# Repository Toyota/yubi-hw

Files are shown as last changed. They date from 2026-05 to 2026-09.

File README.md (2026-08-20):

# YUBI - Yielding Universal Bidigital Interface

### Open Source Hardware for Dexterous Manipulation

<p align="center">
  <a href="https://global.toyota/en/mobility/frontier-research/" target="_blank">
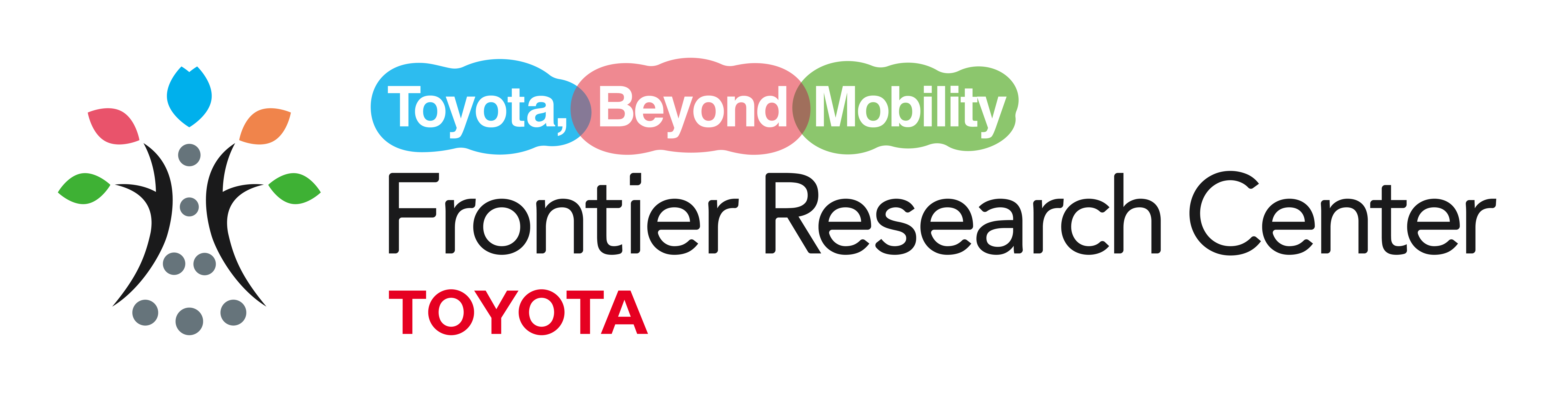
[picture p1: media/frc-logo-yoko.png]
Frontier Research Center, Toyota Motor Corporation
    
  </a>
</p>

<p align="center">
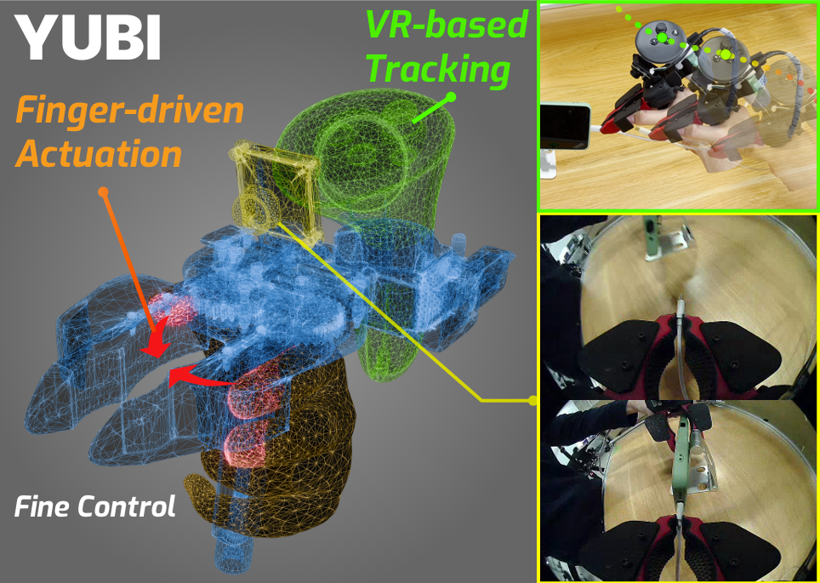
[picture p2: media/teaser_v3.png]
YUBI Overview
  
</p>

🌐 **Project page:** [yubi.airoa.io](https://yubi.airoa.io/)

**YUBI** is a finger-driven dexterous manipulation system developed by Frontier Research Center, Toyota Motor Corporation.

## Part Overview

<p align="center">
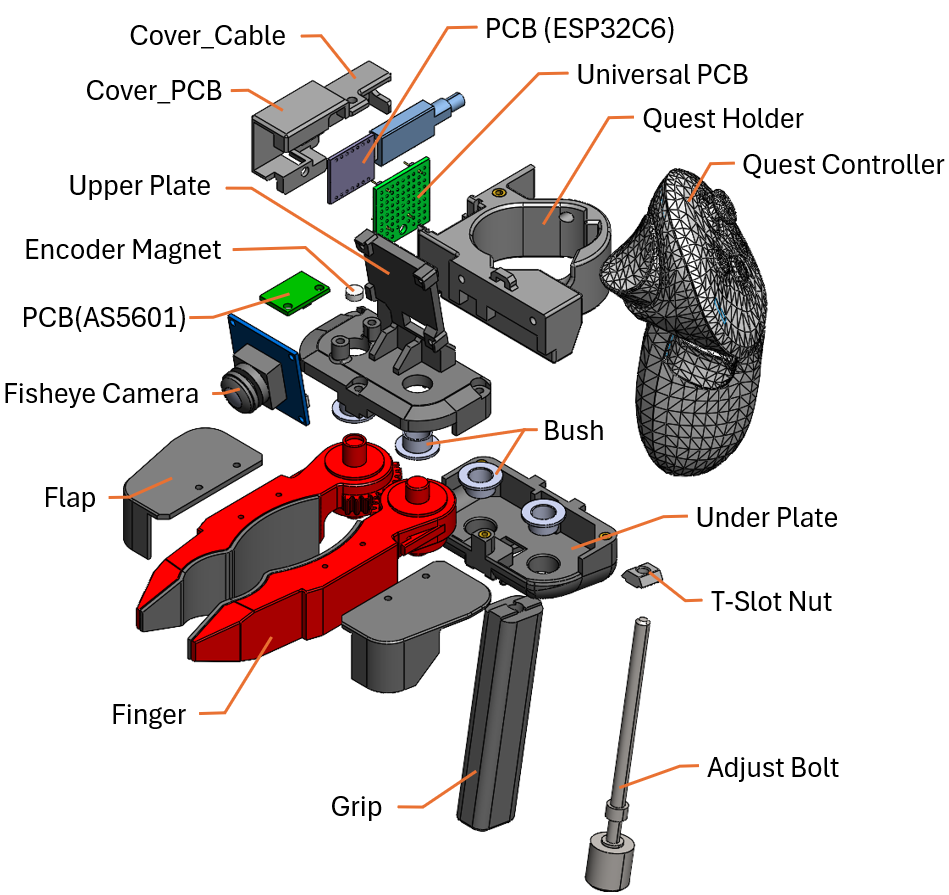
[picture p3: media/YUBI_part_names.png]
YUBI Part Names
  
</p>

- **YUBI Glove** — A wearable device for collecting finger motion data during teleoperation.
- **YUBI Gripper** — A robot-mounted gripper actuated by DYNAMIXEL servos for dexterous manipulation.
- **Stationary data collection desk** — A desk-mounted rig for data collection.
- **Portable data collection rig** — A wearable rig for portable data collection.

<p align="center">
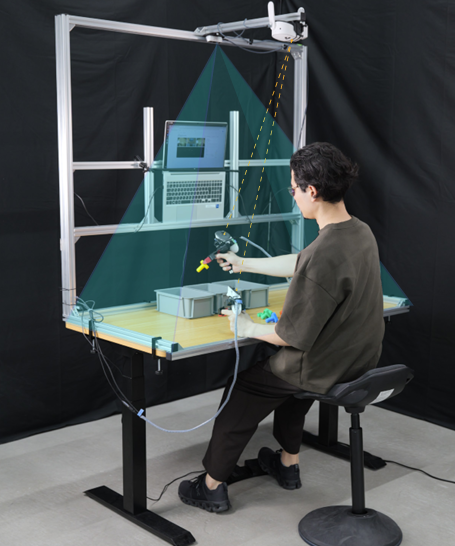
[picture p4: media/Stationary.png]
Stationary data collection desk
  
  &nbsp;&nbsp;
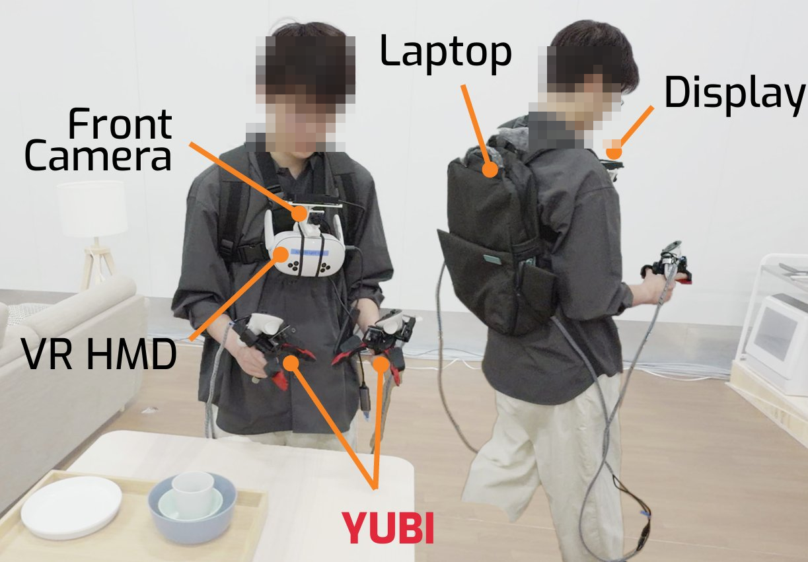
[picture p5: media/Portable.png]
Portable data collection rig
  
</p>

## Repository Structure

```
.
├── STEP/
│   ├── glove/       # YUBI Glove (teleoperation device) STEP files
│   ├── gripper/     # YUBI Gripper (robot-mounted, DYNAMIXEL) STEP files
│   ├── portable/    # Portable data collection rig STEP files
│   └── flange/      # Flange STEP files
├── STL/
│   ├── glove/                  # YUBI Glove STL files (for 3D printing)
│   ├── gripper/                # YUBI Gripper STL files (for 3D printing)
│   ├── portable/               # Portable data collection rig STL files
│   ├── stationary/             # Stationary data collection desk STL files
│   └── flange/                 # Flange STL files
├── docs/
│   ├── BOM/                    # Bill of Materials (CSV)
│   └── AssemblyInstruction/    # Assembly guides (PDF)
└── media/                      # Images for documentation
```

## Supported Robot Flanges

The `flange/` directories provide the parts for mounting the YUBI Gripper to a robot arm. Each supported arm uses a robot-specific flange together with a YUBI-side attachment, as listed below.

| Robot arm | Flange | YUBI-side attachment |
|---|---|---|
| Franka | `FRANKA_FLANGE`  | `YUBI_ATTACHMENT` |
| OpenArm | `OPENARM_FLANGE` | `YUBI_ATTACHMENT` |
| Unitree G1 | `UNITREE_G1_FLANGE` | N/A |

## Getting Started

1. Check the [Bill of Materials](docs/BOM/) to source the required components.
2. 3D print parts using files in the [STL](STL/) directory.
3. Follow the [Assembly Instructions](docs/AssemblyInstruction/) to build the hardware.

## Related Repository

- [yubi-sw](https://github.com/airoa-org/yubi-sw) — Software (control, teleoperation)

## Commercial Use

Commercial manufacturing and sale of products based on YUBI are permitted
subject to CERN-OHL-W v2. See the [Commercial Use Guidelines](COMMERCIAL.md)
for practical guidance.

## Contributors

| Name | Affiliation | Role |
|---|---|---|
| Kazutomo Misao | Frontier Research Center, Toyota Motor Corporation | Project Lead |
| Yoshihiro Okumatsu | Frontier Research Center, Toyota Motor Corporation | Project Sub-Lead |
| Daiki Fukunaga | Frontier Research Center, Toyota Motor Corporation | Mechanical Design |
| Jumpei Arima | Frontier Research Center, Toyota Motor Corporation | Concept Design |
| Yuki Noguchi | Frontier Research Center, Toyota Motor Corporation | Concept Design |
| Makoto Sugiura| AI Robot Association | Data Collection Rig Design |
| Takehiko Ohkawa| AI Robot Association | Data Collection Concept Design |
| Masayoshi Tsuchinaga | Frontier Research Center, Toyota Motor Corporation | Core Maintainer |
| Yusuke Mizuoka | Frontier Research Center, Toyota Motor Corporation | Maintainer |

## Citation

If you use YUBI in your research, please cite:

```bibtex
@misc{ohkawa2026yubi,
      title={{YUBI}: Yielding Universal Bidigital Interface for Bimanual Dexterous Manipulation at Scale},
      author={Takehiko Ohkawa and Jumpei Arima and Yuki Noguchi and Masatoshi Tateno and Makoto Sugiura and Takuya Okubo and Kengo Ikeuchi and Yuma Shin and Hiroki Nishizawa and Naoaki Kanazawa and Yuki Wakayama and Daiki Fukunaga and Koshi Makihara and Tomohiro Motoda and Floris Erich and Yukiyasu Domae and Tatsuya Matsushima and Yoshihiro Okumatsu and Kei Ota},
      year={2026},
      eprint={2606.10244},
      archivePrefix={arXiv},
      primaryClass={cs.RO},
      url={https://arxiv.org/abs/2606.10244},
}
```

## License

This project is licensed under the [CERN Open Hardware Licence Version 2 - Weakly Reciprocal (CERN-OHL-W v2)](LICENSE).

Copyright 2026 Toyota Motor Corporation

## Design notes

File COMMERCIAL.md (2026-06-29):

# Commercial Use Guidelines

This project is released as Open Source Hardware under the
[CERN Open Hardware Licence Version 2 - Weakly Reciprocal
(CERN-OHL-W v2)](LICENSE).

You are free to manufacture, assemble, and sell products based on this
design. However, compliance with the license is required when distributing
Covered Source or products based on it.

This document is a practical summary, not legal advice or a replacement for
the license. If this document and the official license terms differ, the
official license terms control.

## 1. Summary

You are allowed to:

- manufacture products based on this design;
- assemble and sell hardware commercially; and
- integrate this design into larger systems.

When distributing Covered Source or products based on it, you must comply
with the conditions described below and with CERN-OHL-W v2.

## 2. Mandatory Requirements (License Compliance)

### 2.1 License Notice and Attribution

When distributing Covered Source or products based on it, retain the
applicable notices and provide:

- a reference to the CERN-OHL-W v2 license;
- a reference to the original YUBI project; and
- the applicable Source Location.

Example:

```text
This product is based on the YUBI open-source hardware project.
Licensed under CERN-OHL-W v2.
Source: https://github.com/Toyota/yubi-hw
```

### 2.2 Access to Source

When distributing a product based on YUBI, you must either:

- provide each recipient with a copy of the Complete Source; or
- notify each recipient where the Complete Source can be obtained.

For an unmodified YUBI product, the original Source Location is:

<https://github.com/Toyota/yubi-hw>

A Source Location should be a location that you reasonably believe will
remain easily accessible for at least three years, as defined by
CERN-OHL-W v2.

### 2.3 Modifications (If Applicable)

You may modify the design. If you distribute modified Covered Source or a
product based on it:

- you must make the modified Covered Source available as required by the
  license; and
- the modified Covered Source must be licensed under CERN-OHL-W v2 or
  another version permitted by the license.

### 2.4 Change Documentation

When distributing modified Covered Source, you must clearly state:

- who made the changes;
- the date of the changes; and
- a brief description of what was changed.

Example:

```text
Modified by [Company or Individual Name] on [YYYY-MM-DD].
Changes:
- Modified the finger joint geometry
- Reinforced structural components

Modified Source:
https://example.com/path/to/source
```

### 2.5 Copyright Notice

The design files and documentation are copyrighted. You must:

- preserve applicable existing copyright notices; and
- clearly indicate the original copyright holder.

Example:

```text
Copyright 2026 Toyota Motor Corporation
```

Copyright ownership does not prevent use or commercial sale. Rights to use,
make, and sell products are granted subject to CERN-OHL-W v2.

### 2.6 Trademark Usage and Branding

The Toyota name, Toyota logos, and associated marks are protected. This
project and CERN-OHL-W v2 do not grant trademark rights.

You must NOT:

- represent your product as an official Toyota product;
- use Toyota logos in products or marketing without authorization; or
- imply endorsement, certification, sponsorship, or involvement by Toyota
  Motor Corporation.

If you refer to Toyota Motor Corporation or YUBI in product documentation
or marketing, clearly distinguish your product from the original project.
We recommend including a disclaimer such as:

```text
This product is based on the YUBI open-source hardware project.
Toyota Motor Corporation does not endorse or certify this product.
```

Acceptable factual reference:

```text
Based on the YUBI open-source hardware project
```

Unacceptable claims include:

```text
Toyota official product
Toyota-certified hardware
```

## 3. What You Are Allowed to Do

Subject to CERN-OHL-W v2 and any other applicable rights, you may:

- sell assembled hardware products;
- set your own price;
- combine YUBI with proprietary components or systems; and
- use, make, offer to sell, sell, import, and otherwise transfer products
  based on the Covered Source.

No royalties are required by Toyota Motor Corporation for rights granted
under CERN-OHL-W v2.

## 4. What You Are Not Required to Do

CERN-OHL-W v2 does not necessarily require you to:

- open source your entire product;
- open source unrelated components or External Material.

Modified Covered Source remains subject to the license requirements.
Available Components and External Material are treated according to the
definitions and conditions in CERN-OHL-W v2.

## 5. Safety and Liability

The original authors provide the Covered Source and products "as is",
without warranties, as described in CERN-OHL-W v2.

If you manufacture, distribute, or sell a product based on YUBI, you are
responsible for:

- product quality;
- product safety;
- testing and quality assurance;
- compliance with applicable laws, regulations, and standards; and
- claims, warranties, and support offered for your product.

Example:

```text
This product is provided by [Company Name].
The original authors are not responsible for its safety or liability.
```

## 6. Recommended Best Practices

Although not required, we encourage:

- contributing improvements back to the project;
- publishing modified designs publicly; and
- providing clear documentation to users.

## 7. Contact for Commercial Use

If you plan to manufacture or sell products based on YUBI, we kindly ask
that you contact us:

<yubi-contact@mail.toyota.co.jp>

This contact request is voluntary and is not an additional condition of
CERN-OHL-W v2. Contacting us does not constitute approval, certification,
endorsement, or a separate commercial license.

## 8. Final Note

These guidelines are intended to help companies correctly apply
CERN-OHL-W v2 when using YUBI commercially.

For the official license terms, refer to:

<https://cern-ohl.web.cern.ch/>

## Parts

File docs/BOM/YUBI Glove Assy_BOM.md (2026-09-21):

# csv→md

| YUBI Glove Assy_ver.2_PARTS LIST |  |  |  |  |  |  |  |  |  |
| --- | --- | --- | --- | --- | --- | --- | --- | --- | --- |
| (This BOM contains all parts required to build one YUBI Glove. Select either Right-hand or Left-hand specific parts according to your intended configuration) |  |  |  |  |  |  |  |  |  |
|  |  |  |  |  |  |  |  |  |  |
| ・STANDARD PARTS |  |  |  |  |  |  |  |  |  |
| No. | PART No. | TYPE | PART NAME | Qty. | MATERIAL | Buy(JP) | Link | REMARKS | FILE NAME (STL/STEP) |
| 1 | UPPER PLATE_CAMERA BKT | 3D-PRINTED | UPPER PLATE | 1 | PLA_BLACK | - | - |  | UPPER PLATE_CAMERA BKT |
| 2 | UNDER PLATE | 3D-PRINTED | UNDER PLATE | 1 | PLA_BLACK | - | - |  | UNDER PLATE |
| 3 | FINGER with Gear_t30_R | 3D-PRINTED | FINGER with Gear_t30_R | 1 | PLA_RED | - | - | for Right-hand / Outer side | FINGER with Gear_t30_R |
| 4 | FINGER with Gear_t20_L | 3D-PRINTED | FINGER with Gear_t20_L | 1 | PLA_RED | - | - | for Right-hand / Inner side | FINGER with Gear_t20_L |
| 5 | FINGER with Gear_t30_L | 3D-PRINTED | FINGER with Gear_t30_L | 1 | PLA_RED | - | - | for Left-hand / Outer side | FINGER with Gear_t30_L |
| 6 | FINGER with Gear_t20_R | 3D-PRINTED | FINGER with Gear_t20_R | 1 | PLA_RED | - | - | for Left-hand / Inner side | FINGER with Gear_t20_R |
| 7 | FLAP_R | 3D-PRINTED | FLAP_R | 1 | PLA_BLACK | - | - |  | FLAP_R |
| 8 | FLAP_L | 3D-PRINTED | FLAP_L | 1 | PLA_BLACK | - | - |  | FLAP_L |
| 9 | GRIP | 3D-PRINTED | GRIP | 1 | PLA_BLACK | - | - |  | GRIP |
| 10 | HOLDER_Quest_R | 3D-PRINTED | HOLDER_Quest_R | 1 | PLA_BLACK | - | - | for Right-hand | HOLDER_Quest_R |
| 11 | COVER_PCB_R | 3D-PRINTED | COVER_PCB_R | 1 | PLA_BLACK | - | - | for Right-hand | COVER_PCB_R |
| 12 | COVER_CABLE_R | 3D-PRINTED | COVER_CABLE_R | 1 | PLA_BLACK | - | - | for Right-hand | COVER_CABLE_R |
| 13 | HOLDER_Quest_L | 3D-PRINTED | HOLDER_Quest_L | 1 | PLA_BLACK | - | - | for Left-hand | HOLDER_Quest_L |
| 14 | COVER_PCB_L | 3D-PRINTED | COVER_PCB_L | 1 | PLA_BLACK | - | - | for Left-hand | COVER_PCB_L |
| 15 | COVER_CABLE_L | 3D-PRINTED | COVER_CABLE_L | 1 | PLA_BLACK | - | - | for Left-hand | COVER_CABLE_L |
| 16 | MetaQuestTouchPlus_R | STANDARD | MetaQuestTouchPlus Controller_R | 1 | N/A | amazon | [https://www.amazon.co.jp/dp/B09MJQKS5D?ref=fed_asin_title](https://www.amazon.co.jp/dp/B09MJQKS5D?ref=fed_asin_title) | Right / Standard controller for YUBI (used with Quest 3S) |  |
| 17 | MetaQuestTouchPlus_L | STANDARD | MetaQuestTouchPlus Controller_L | 1 | N/A | amazon | [https://www.amazon.co.jp/dp/B09MJQKS5D?ref=fed_asin_title](https://www.amazon.co.jp/dp/B09MJQKS5D?ref=fed_asin_title) | Left / Standard controller for YUBI (used with Quest 3S) |  |
| 18 | USB CAMERA_ELP-USBFHD01M-L180 | STANDARD | CAMERA | 1 | N/A | ELP | [https://www.webcamerausb.com/elp-high-fps-fisheye-usb-camera-module-with-cmos-ov2710-image-sensor-full-hd-1080p-usb20-web-camerawide-angle-usb-with-camera-p-85.html](https://www.webcamerausb.com/elp-high-fps-fisheye-usb-camera-module-with-cmos-ov2710-image-sensor-full-hd-1080p-usb20-web-camerawide-angle-usb-with-camera-p-85.html) |  |  |
| 19 | ESP32C6 | STANDARD | PCB (ESP32C6) | 1 | N/A | amazon | [https://www.amazon.co.jp/dp/B0FX9MN62Z?ref=fed_asin_title](https://www.amazon.co.jp/dp/B0FX9MN62Z?ref=fed_asin_title) |  |  |
| 20 | AS5601 | STANDARD | PCB (AS5601) | 1 | N/A | switch-science | [https://www.switch-science.com/products/3494](https://www.switch-science.com/products/3494) |  |  |
| 21 | NEODYMIUM MAGNET | STANDARD | NEODYMIUM MAGNET_AS5601 | 1 | N/A | - | - | Included with AS5601 sensor |  |
| 22 | UNIVERSAL PCB | STANDARD | UNIVERSAL PCB | 1 | N/A | digikey | [08808 SparkFun Electronics | 穴あきプロトタイプボード | DigiKey](https://www.digikey.jp/ja/products/detail/sparkfun-electronics/08808/7387401) |  |  |
| 23 | PIN HEADER | STANDARD | PIN HEADER | 4 | N/A | - | - | included with ESP32C6 |  |
| 24 | USB CABLE TYPE-C | STANDARD | USB CABLE TYPE-C | 2 | N/A | amazon | [https://www.amazon.co.jp/dp/B08XJP9GMP?ref=fed_asin_title&th=1](https://www.amazon.co.jp/dp/B08XJP9GMP?ref=fed_asin_title&th=1) |  |  |
| 25 | CB2-6 | STANDARD | CAP BOLT | 4 | SCM435 | MISUMI |  |  |  |
| 26 | CB2.5-6 | STANDARD | CAP BOLT | 2 | SCM435 | MISUMI |  |  |  |
| 27 | CB2.5-8 | STANDARD | CAP BOLT | 2 | SCM435 | MISUMI |  |  |  |
| 28 | CB2.5-15 | STANDARD | CAP BOLT | 3 | SCM435 | MISUMI |  |  |  |
| 29 | CB3-6 | STANDARD | CAP BOLT | 1 | SCM435 | MISUMI |  |  |  |
| 30 | CBSTNR3-5 | STANDARD | ULTRA LOW HEAD CAP BOLT | 2 | SCM435 | MISUMI |  |  |  |
| 31 | LRLM3-6 | STANDARD | KNURLED BOLT | 1 | SCM435 | MISUMI |  |  |  |
| 32 | AJKTNS5-70 | STANDARD | ADJUST BOLT | 1 | S45C | MISUMI |  |  |  |
| 33 | HNTT5-5 | STANDARD | T-SLOT NUT | 1 | S10C | MISUMI |  |  |  |
| 34 | SB-264040 | STANDARD | INSERT | 5 | BRASS | MISUMI |  |  |  |
| 35 | SB-304540 | STANDARD | INSERT | 2 | BRASS | MISUMI |  |  |  |
| 36 | JZF8-5 | STANDARD | BUSH | 4 | POM | MISUMI | [https://jp.misumi-ec.com/vona2/detail/110302640340/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](https://jp.misumi-ec.com/vona2/detail/110302640340/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) |  |  |
| 37 | PX-10H15_HYPER V SHEET | STANDARD | RUBBER SHEET_R | 1 | HYPER V SHEET | MISUMI/ | [https://jp.misumi-ec.com/vona2/detail/223013695214/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](https://jp.misumi-ec.com/vona2/detail/223013695214/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) |  |  |
| 38 | PX-10H15_HYPER V SHEET | STANDARD | RUBBER SHEET_L | 1 |  | NISSHINRUBBER | [https://nisshinrubber-metalcraft.com/products/hyperv%E3%82%B7%E3%83%BC%E3%83%88-px-10h-15-%E8%80%90%E6%B2%B9w270-l270-h1-5mm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](https://nisshinrubber-metalcraft.com/products/hyperv%E3%82%B7%E3%83%BC%E3%83%88-px-10h-15-%E8%80%90%E6%B2%B9w270-l270-h1-5mm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) |  |  |
| 39 | RUBBER BAND No.16 | STANDARD | RUBBER BAND No.16 | 1 | RUBBER | amazon | [https://www.amazon.co.jp/%E3%82%AA%E3%83%BC%E3%83%90%E3%83%B3%E3%83%89-100g%E7%AE%B1-GE-011-%E5%A4%A9%E7%84%B6%E3%82%B4%E3%83%A0-%E5%B0%8F%E3%81%95%E3%81%84%E6%A8%99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](https://www.amazon.co.jp/%E3%82%AA%E3%83%BC%E3%83%90%E3%83%B3%E3%83%89-100g%E7%AE%B1-GE-011-%E5%A4%A9%E7%84%B6%E3%82%B4%E3%83%A0-%E5%B0%8F%E3%81%95%E3%81%84%E6%A8%99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) |  |  |
|  |  |  |  |  |  |  | Note:
These links are provided for convenience only.
Toyota does not endorse specific vendors or guarantee the quality, availability, or accuracy of the listed products. |  |  |
|  |  |  |  |  |  |  |  |  |  |
| ・OPTION PARTS |  |  |  |  |  |  |  |  |  |
| No. | PART No. | TYPE | PART NAME | Qty. | MATERIAL | Buy(JP) | Website | REMARKS | FILE NAME (STL/STEP) |
| 101 | FINGER ATTACHMENT_Glove_R | 3D-PRINTED | FINGER ATTACHMENT_Glove_R | 1 | PLA_BLACK | - |  |  | FINGER ATTACHMENT_Glove_R |
| 102 | FINGER ATTACHMENT_Glove_L | 3D-PRINTED | FINGER ATTACHMENT_Glove_L | 1 | PLA_BLACK | - |  |  | FINGER ATTACHMENT_Glove_L |
| 103 | FINGER PAD_t30_R | 3D-PRINTED | FINGER PAD_t30_R | 1 | PLA_RED | - |  | for Right-hand / Outer side | FINGER PAD_t30_R |
| 104 | FINGER PAD_t30_L | 3D-PRINTED | FINGER PAD_t30_L | 1 | PLA_RED | - |  | for Left-hand / Outer side | FINGER PAD_t30_L |
| 105 | FINGER PAD_t20 | 3D-PRINTED | FINGER PAD_t20 | 1 | PLA_RED | - |  | reversible | FINGER PAD_t20 |
| 106 | FINGER PAD_t30_R_v2 | 3D-PRINTED | FINGER PAD_t30_R_v2 | 1 | PLA_RED | - |  | for Right-hand / Outer side | FINGER PAD_t30_R_v2 |
| 107 | FINGER PAD_t30_L_v2 | 3D-PRINTED | FINGER PAD_t30_L_v2 | 1 | PLA_RED | - |  | for Left-hand / Outer side | FINGER PAD_t30_L_v2 |
| 108 | FINGER PAD_t20_v2 | 3D-PRINTED | FINGER PAD_t20_v2 | 1 | PLA_RED | - |  | reversible | FINGER PAD_t20_v2 |
| 109 | FIN | 3D-PRINTED | FIN | 2 | TPU_ORANGE | - |  | reversible / for FINGER PAD_v2 | FIN |
| 110 | CB2.5-10 | STANDARD | CAP BOLT | 4 | SCM435 | MISUMI |  |  |  |

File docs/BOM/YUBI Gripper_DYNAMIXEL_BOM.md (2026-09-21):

# csv→md

| YUBI Gripper Assy_DYNAMIXEL_ver.2_PARTS LIST |  |  |  |  |  |  |  |  |  |
| --- | --- | --- | --- | --- | --- | --- | --- | --- | --- |
|  |  |  |  |  |  |  |  |  |  |
| No. | PART No. | TYPE | PART NAME | Qty. | MATERIAL | Buy(JP) | Link | REMARKS | FILE NAME (STL/STEP) |
| 1 | UPPER PLATE_CAMERA BKT | 3D-PRINTED | UPPER PLATE | 1 | PLA_BLACK | - |  |  | UPPER PLATE_CAMERA BKT |
| 2 | CASE | 3D-PRINTED | CASE | 1 | PLA_BLACK | - |  |  | CASE |
| 3 | BRACKET_DYNAMIXEL | 3D-PRINTED | BRACKET_DYNAMIXEL | 1 | PLA_BLACK | - |  |  | BRACKET_DYNAMIXEL |
| 4 | FINGER PAD_t30_R | 3D-PRINTED | FINGER PAD_t30_R | 1 | PLA_RED | - |  | for Right-hand / Outer side | FINGER PAD_t30_R |
| 5 | FINGER PAD_t30_L | 3D-PRINTED | FINGER PAD_t30_L | 1 | PLA_RED | - |  | for Left-hand / Outer side | FINGER PAD_t30_L |
| 6 | FINGER PAD_t20 | 3D-PRINTED | FINGER PAD_t20 | 1 | PLA_RED | - |  | reversible | FINGER PAD_t20 |
| 7 | FLAP_R | 3D-PRINTED | FLAP_R | 1 | PLA_BLACK | - |  |  | FLAP_R |
| 8 | FLAP_L | 3D-PRINTED | FLAP_L | 1 | PLA_BLACK | - |  |  | FLAP_L |
| 9 | FINGER ATTACHMENT_R | MACHINED OR PRINTED | FINGER ATTACHMENT_R | 1 | A2024 / PLA_BLACK | MACHINED/3D printing |  |  | FINGER ATTACHMENT_R |
| 10 | FINGER ATTACHMENT_L | MACHINED OR PRINTED | FINGER ATTACHMENT_L | 1 | A2024 / PLA_BLACK | MACHINED/3D printing |  |  | FINGER ATTACHMENT_L |
| 11 | GEAR SHAFT | MACHINED | GEAR SHAFT | 1 | A2024 | MACHINED |  |  | GEAR SHAFT |
| 12 | DYNAMIXEL XM430-W350-R | STANDARD | SERVO MOTOR (DYNAMIXEL XM430-W350-R) | 1 | N/A | ROBOTIS | [https://e-shop.robotis.co.jp/product.php?id=44](https://e-shop.robotis.co.jp/product.php?id=44) |  |  |
| 13 | USB CAMERA_ELP-USBFHD01M-L180 | STANDARD | CAMERA | 1 | N/A | ELP | [https://www.webcamerausb.com/elp-high-fps-fisheye-usb-camera-module-with-cmos-ov2710-image-sensor-full-hd-1080p-usb20-web-camerawide-angle-usb-with-camera-p-85.html](https://www.webcamerausb.com/elp-high-fps-fisheye-usb-camera-module-with-cmos-ov2710-image-sensor-full-hd-1080p-usb20-web-camerawide-angle-usb-with-camera-p-85.html) |  |  |
| 14 | GEAKB1.0-30-6-B-8N-QFC17-M3-LL | STANDARD | SPUR GEAR_z30 | 2 | S45C | MISUMI |  |  |  |
| 15 | SSFRHQ8-20-F6-P5-T6-Q5-KC8-A12 | STANDARD | SHAFT D8 | 1 | SUS304 | MISUMI |  |  |  |
| 16 | MTA05-13ZZ DBS | STANDARD | BEARING | 3 | SUS | MISUMI |  |  |  |
| 17 | WSSAB10-5-1 | STANDARD | WASHER | 3 | A2017 | MISUMI |  |  |  |
| 18 | KEG3-8 | STANDARD | PARALLEL KEY | 2 | S45C | MISUMI |  |  |  |
| 19 | CBSTNR2-5 | STANDARD | ULTRA LOW HEAD CAP BOLT | 8 | SCM435 | MISUMI |  |  |  |
| 20 | CBSTNR2.5-6 | STANDARD | ULTRA LOW HEAD CAP BOLT | 1 | SCM435 | MISUMI |  |  |  |
| 21 | CBSTNR3-8 | STANDARD | ULTRA LOW HEAD CAP BOLT | 4 | SCM435 | MISUMI |  |  |  |
| 22 | CB2-6 | STANDARD | CAP BOLT | 4 | SCM435 | MISUMI |  |  |  |
| 23 | CB2.5-6 | STANDARD | CAP BOLT | 2 | SCM435 | MISUMI |  |  |  |
| 24 | CB2.5-10 | STANDARD | CAP BOLT | 4 | SCM435 | MISUMI |  |  |  |
| 25 | CB2.5-15 | STANDARD | CAP BOLT | 7 | SCM435 | MISUMI |  |  |  |
| 26 | SB-304550 | STANDARD | INSERT | 4 | BRASS | MISUMI |  |  |  |
| 27 | SB-264040 | STANDARD | INSERT | 5 | BRASS | MISUMI |  |  |  |
| 28 | SB-203030 | STANDARD | INSERT | 4 | BRASS | MISUMI |  |  |  |
| 29 | JPBPB2-3 | STANDARD | PIN, LOCATING | 1 | SKS3 | MISUMI |  |  |  |
| 30 | JPDPB2-3 | STANDARD | PIN, LOCATING | 1 | SKS3 | MISUMI |  |  |  |
| 31 | PX-10H15_HYPER V SHEET | STANDARD | RUBBER SHEET_R | 1 | HYPER V SHEET | MISUMI/ | [https://jp.misumi-ec.com/vona2/detail/223013695214/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](https://jp.misumi-ec.com/vona2/detail/223013695214/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) |  |  |
| 32 | PX-10H15_HYPER V SHEET | STANDARD | RUBBER SHEET_L | 1 | HYPER V SHEET | NISSHINRUBBER | [https://nisshinrubber-metalcraft.com/products/hyperv%E3%82%B7%E3%83%BC%E3%83%88-px-10h-15-%E8%80%90%E6%B2%B9w270-l270-h1-5mm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](https://nisshinrubber-metalcraft.com/products/hyperv%E3%82%B7%E3%83%BC%E3%83%88-px-10h-15-%E8%80%90%E6%B2%B9w270-l270-h1-5mm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) |  |  |
| 33 | BRACKET_GRIPPER | MACHINED | BRACKET_GRIPPER | 1 | A2024 | MACHINED |  | for attachment to the UR5e | BRACKET_GRIPPER |
| 34 | UR5e_FLANGE | MACHINED | UR5e_FLANGE | 1 | A2024 | MACHINED |  | for attachment to the UR5e | UR5e_FLANGE |
| 35 | CBE3-8 | STANDARD | CAP BOLT | 8 | SCM435 | MISUMI |  | for attachment to the UR5e |  |
| 36 | CBE6-10 | STANDARD | CAP BOLT | 4 | SCM435 | MISUMI |  | for attachment to the UR5e |  |
| 37 | XDSHC6-P4-L6-B5 | STANDARD | PIN, LOCATING | 1 | SUS316L | MISUMI |  | for attachment to the UR5e |  |
| 38 | JPBPB2-3 | STANDARD | PIN, LOCATING | 1 | SKS3 | MISUMI |  | for attachment to the UR5e |  |
| 39 | JPDPB2-3 | STANDARD | PIN, LOCATING | 1 | SKS3 | MISUMI |  | for attachment to the UR5e |  |
|  |  |  |  |  |  |  | Note:
These links are provided for convenience only.
Toyota does not endorse specific vendors or guarantee the quality, availability, or accuracy of the listed products. |  |  |

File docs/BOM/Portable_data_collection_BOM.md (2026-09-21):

| YUBI Portable data collection rig_PARTS LIST |  |  |  |  |  |  |  |  |  |
| --- | --- | --- | --- | --- | --- | --- | --- | --- | --- |
|  |  |  |  |  |  |  |  |  |  |
|  |  |  |  |  |  |  |  |  | Note:
These links are provided for convenience only.
Toyota does not endorse specific vendors or guarantee the quality, availability, or accuracy of the listed products. |
| No. | PART No. | TYPE | PART NAME | Qty. | MATERIAL | REMARKS | FILE NAME (STL/STEP) | Vendor | Link |
| 1 | chest_mount_3s_hmd | 3D-PRINTED | chest_mount_3s_hmd | 1 | ABS |  | chest_mount_3s_hmd |  |  |
| 2 | Display_case | 3D-PRINTED | Display_case | 1 | ABS |  | Display_case |  |  |
| 3 | Display_plate | 3D-PRINTED | Display_plate | 1 | ABS |  | Display_plate |  |  |
| 4 |  | STANDARD | Laptop | 1 |  |  |  |  |  |
| 5 |  | STANDARD | Quest 3s | 1 |  | 128GB |  | amazon | https://amzn.asia/d/asShIRH |
| 6 | 2.02E+09 | STANDARD | 3.5 inch display | 1 |  |  |  | amazon | https://www.amazon.co.jp/dp/B0DRF9Q566 |
| 7 | ELP-USBFHD01M-L180 | STANDARD | Wrist Camera | 2 |  |  |  | alibaba | https://japanese.alibaba.com/product-detail/ELP-USB-Fisheye-Camera-Wide-angle-1601061809265.html |
| 8 | U3H-H043BK/E | STANDARD | USB hub | 2 |  |  |  | amazon | https://www.amazon.co.jp/dp/B0DVGPF6D5 |
| 9 | Anker 332 | STANDARD | USB-C hub | 1 |  |  |  | amazon | https://www.amazon.co.jp/dp/B0BQMSXFP7 |
| 10 | RAD56 | STANDARD | USB cable C-C (2-pack) | 1 |  |  |  | amazon | https://www.amazon.co.jp/dp/B0CX56FJJ6 |
| 11 | 10495 | STANDARD | USB-A extension cable (1m) | 1 |  |  |  | amazon | https://www.amazon.co.jp/dp/B086ZGYCLD |
| 12 | 10550 | STANDARD | micro HDMI to HDMI cable (1m) | 1 |  |  |  | amazon | https://www.amazon.co.jp/dp/B08P5QSG5M |
| 13 | UG-USBC-25052 | STANDARD | USB Type C to RJ45 | 1 |  |  |  | amazon | https://www.amazon.co.jp/dp/B0CD1FDKT1 |
| 14 | 80421 | STANDARD | LAN cable (1m) | 1 |  |  |  | amazon | https://www.amazon.co.jp/dp/B086DPWMQM |
| 15 | BQ-CC71AM-K | STANDARD | Rechargeable battery & charger set | 1 |  |  |  | amazon | https://amzn.asia/d/0atTDXjR |
| 16 | CB2.5-4 | STANDARD | Hex socket bolt | 2 | SCM435 |  |  | misumi | https://jp.misumi-ec.com/vona2/detail/110300239070/?PNSearch=CB2.5-4 |
| 17 | CB3-6 | STANDARD | Hex socket bolt | 2 | SCM435 |  |  | misumi | https://jp.misumi-ec.com/vona2/detail/110300239070/?HissuCode=CB3-6 |
| 18 | SKNTR5 | STANDARD | M5 nut | 1 |  |  |  | misumi | https://jp.misumi-ec.com/vona2/detail/110300250540/ |
| 19 | CINSTAV/E | STANDARD | Chest strap | 1 |  |  |  | insta360 | https://store.insta360.com/jp/product/chest_strap?c=2034&from=accessory |
| 20 |  | STANDARD | Rubber cord | 1 |  |  |  | amazon | https://www.amazon.co.jp/dp/B08KXVQFQF |
| 21 | DGB-S043BK | STANDARD | Backpack | 1 |  |  |  | amazon | https://www.amazon.co.jp/dp/B095RLRDGR |

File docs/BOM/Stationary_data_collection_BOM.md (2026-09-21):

| YUBI Stationary data collection desk_PARTS LIST |  |  |  |  |  |  |  |  |  |
| --- | --- | --- | --- | --- | --- | --- | --- | --- | --- |
|  |  |  |  |  |  |  |  |  |  |
|  |  |  |  |  |  |  |  |  | Note:
These links are provided for convenience only.
Toyota does not endorse specific vendors or guarantee the quality, availability, or accuracy of the listed products. |
| No. | PART No. | TYPE | PART NAME | Qty. | MATERIAL | REMARKS | FILE NAME (STL/STEP) | Vendor | Link |
| 1 | Quest_mount | 3D-PRINTED | Quest_mount | 1 | PLA_BLACK |  | Quest_mount |  |  |
| 2 | realsense435_mount | 3D-PRINTED | realsense435_mount | 1 | PLA_BLACK |  | realsense435_mount |  |  |
| 3 |  | STANDARD | Laptop | 1 |  |  |  |  |  |
| 4 |  | STANDARD | Quest 3s | 1 |  | 128GB |  | amazon | https://amzn.asia/d/asShIRH |
| 5 |  | STANDARD | Realsense435i | 1 |  |  |  | amazon | https://www.amazon.co.jp/dp/B07MWR2YJB |
| 6 | U3H-H043BK/E | STANDARD | USB hub | 2 |  |  |  | amazon | https://www.amazon.co.jp/dp/B0DVGPF6D5 |
| 7 | PQUSB102401 | STANDARD | USB cable A-C | 4 |  |  |  | amazon | https://www.amazon.co.jp/dp/B0CLPG8Z4T |
| 8 | RAD56 | STANDARD | USB cable C-C (2-pack) | 1 |  |  |  | amazon | https://www.amazon.co.jp/dp/B0CX56FJJ6 |
| 9 | LB-6C6S | STANDARD | Power strip | 1 |  |  |  | amazon | https://www.amazon.co.jp/SAYBOUR-%E5%80%8B%E5%88%A5%E3%82%B9%E3%82%A4%E3%83%83%E3%83%81-%E9%9B%B7%E3%82%AC%E3%83%BC%E3%83%89%E7%AF%80%E9%9B%BB%E3%82%BF%E3%83%83%E3%8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 |
| 10 | BQ-CC71AM-K | STANDARD | Rechargeable battery & charger set | 1 |  |  |  | amazon | https://amzn.asia/d/0atTDXjR |
| 11 | HFS6-3030-1340 | STANDARD | HFS6-3030-1340 | 2 |  | Series 6, Square 30x30mm, 1-row slot, 4-side slot |  | misumi |  |
| 12 | HFS6-3030-730 | STANDARD | HFS6-3030-730 | 2 |  | Series 6, Square 30x30mm, 1-row slot, 4-side slot |  | misumi |  |
| 13 | NEFS6-3030-1400 | STANDARD | NEFS6-3030-1400 | 1 |  | Series 6, N-type, Square 30x30mm, 1-row slot, 4-side slot |  | misumi |  |
| 14 | NEFS6-3030-500 | STANDARD | NEFS6-3030-500 | 2 |  | Series 6, N-type, Square 30x30mm, 1-row slot, 4-side slot |  | misumi |  |
| 15 | NEFS6-3030-625.5 | STANDARD | NEFS6-3030-625.5 | 1 |  | Series 6, N-type, Square 30x30mm, 1-row slot, 4-side slot |  | misumi |  |
| 16 | NEFS6-3060-1200 | STANDARD | NEFS6-3060-1200 | 2 |  | Series 6, N-type, Rectangular 30x60mm, 2-row slot, 4-side slot |  | misumi |  |
| 17 | NEFS6-3060-1340 | STANDARD | NEFS6-3060-1340 | 2 |  | Series 6, N-type, Rectangular 30x60mm, 2-row slot, 4-side slot |  | misumi |  |
| 18 | HBLFSD6 | STANDARD | HBLFSD6 | 10 |  | Reverse bracket with protrusion |  | misumi |  |
| 19 | HBLFSN6 | STANDARD | HBLFSN6 | 31 |  | Reverse bracket with protrusion |  | misumi |  |
| 20 | CBM6-12 | STANDARD | CBM6-12 | 100 | SCM435 | Hex socket bolt for aluminum frame |  | misumi |  |
| 21 | GFC6-3030-B | STANDARD | GFC6-3030-B | 7 |  | Series 6 (slot width 8mm), frame cap for aluminum frame |  | misumi |  |
| 22 | HFC6-3060-B | STANDARD | HFC6-3060-B | 2 |  | Series 6 (slot width 8mm), frame cap for aluminum frame |  | misumi |  |
| 23 | HNTP6-6 | STANDARD | HNTP6-6 | 100 |  | Series 6 (slot width 8mm), post-insert spring nut for 30/60 square aluminum frame |  | misumi |  |
| 24 |  | STANDARD | Foot pedal | 1 |  |  |  | amazon | https://amzn.asia/d/2aQH9AC |
| 25 | C-clamp | STANDARD | Clamp (2-pack) | 3 |  |  |  | amazon | https://www.amazon.co.jp/Refoiner-%E3%83%84%E3%83%BC%E3%83%AB%E5%9B%BA%E5%AE%9A%E7%94%A8/dp/B0FMDF4FQL |
| 26 | SKG-R1070BK | STANDARD | Rubber rope with J-hooks on both ends | 1 |  |  |  | misumi | https://jp.misumi-ec.com/vona2/detail/223013895687/ |
| 27 | AB200-W Black | STANDARD | Cable ties | 1 |  |  |  | amazon | https://www.amazon.co.jp/dp/B000THQ4ZO |
| 28 |  | STANDARD | Rubber cord | 1 |  |  |  | amazon | https://www.amazon.co.jp/dp/B08KXVQFQF |
| 29 | E7 | STANDARD | Flexispot E7 standing desk (top 140x70) | 1 |  |  |  | flexispot | https://www.flexispot.jp/e7-set.html?srsltid=AfmBOopAdXlEPLmeXNZ6NbJayiAJpXR7XQ8RgopcW_UmOQsH_2Mnfeve |

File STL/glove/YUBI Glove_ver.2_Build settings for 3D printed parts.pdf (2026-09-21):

YUBI Glove_ver.2 _ Build settings for 3D printed parts

STL file name | Wall loops | Sparse infill density | Printing orientation
UPPER PLATE_CAMERA BKT.stl | 3 | 30% or more

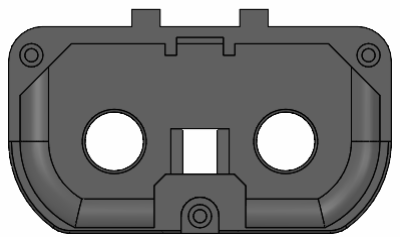
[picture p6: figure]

UNDER PLATE_v2.stl | 3 | 30% or more

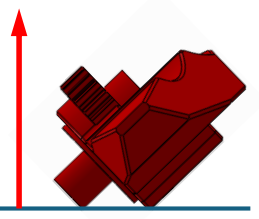
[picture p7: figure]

FINGER with Gear_t30/t20_L.stl | 3 | 50% or more
FINGER with Gear_t30/t20_R.stl | 3 | 50% or more

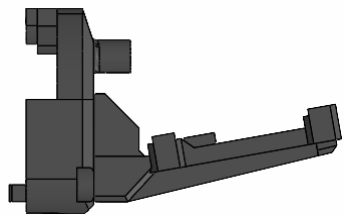
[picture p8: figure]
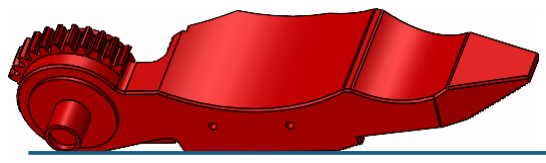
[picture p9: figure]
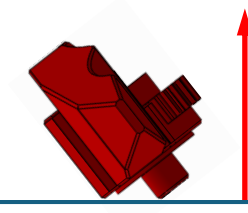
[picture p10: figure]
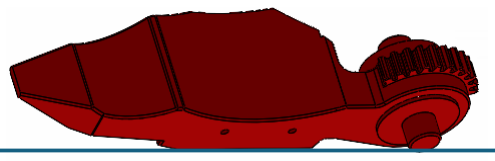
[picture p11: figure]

Other STL data | default | default | Automatic placement is acceptable.

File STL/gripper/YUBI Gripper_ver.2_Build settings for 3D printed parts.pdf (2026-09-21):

YUBI Gripper_ver.2 _ Build settings for 3D printed parts

STL file name | Wall loops | Sparse infill density | Printing orientation
UPPER PLATE_CAMERA BKT.stl | 3 | 50% or more
CASE.stl | 3 | 50% or more

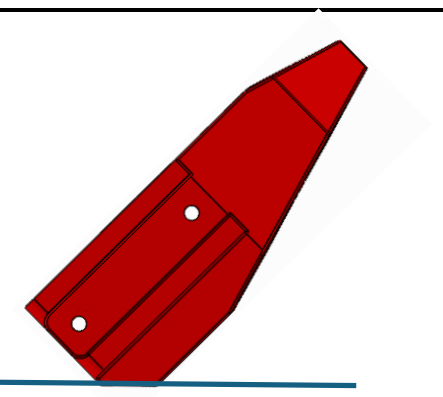
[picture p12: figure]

FINGER PAD_t30_L.stl FINGER PAD_t30_R.stl | 3 | 50% or more
FINGER PAD_t20.stl | 3 | 50% or more

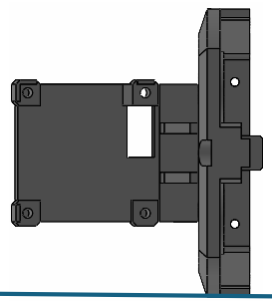
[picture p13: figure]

Other STL data | default | default | Automatic placement is acceptable.

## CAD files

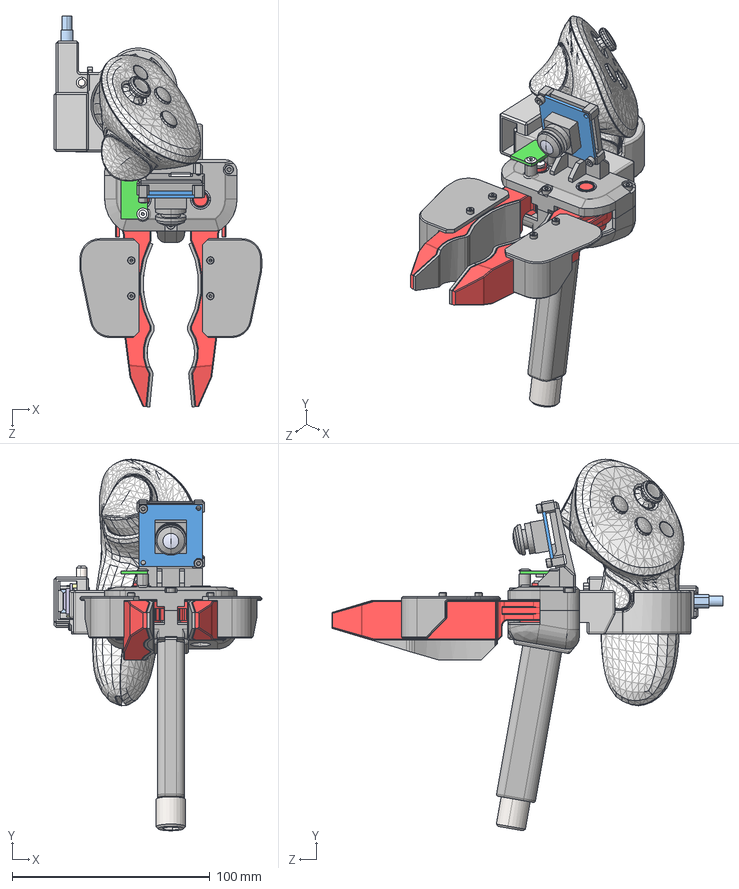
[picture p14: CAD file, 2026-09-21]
STEP/glove/YUBI Glove Assy_ver2_R.STEP
105.0 x 188.0 x 197.8 mm
UNDER PLATE_v2_INSERT TYPE
UPPER PLATE_CAMERA BKT_12bit_AS5601_v2_INSERT TYPE
FINGER with Gear_Glove_t30_R_SHAFT DIA Φ8
FINGER with Gear_Glove_t20_L_SHAFT DIA Φ8
RUBBER SHEET_t30_R
RUBBER SHEET_t20
AS5601
HNTT5-5
GRIP
AJKTNS5-70
USB CAMERA_ELP-USBFHD01M-L180
CBSTNR3-5 x 2
MAGNET_D6_AS5601
FLAP_R
FLAP_L
HOLDER_Quest_45deg_R_INSERT TYPE
COVER1_R
COVER2_R
ESP32
UNIVERSAL PCB
CB2.5-15 x 3
CB2.5-8 x 2
CB3-6
LRLM3-6
CB2-6 x 4
CB2.5-6 x 2
MetaQuestTouchPlus_Right
JZF8-5 x 4
SB-264040 x 5
SB-304540 x 2

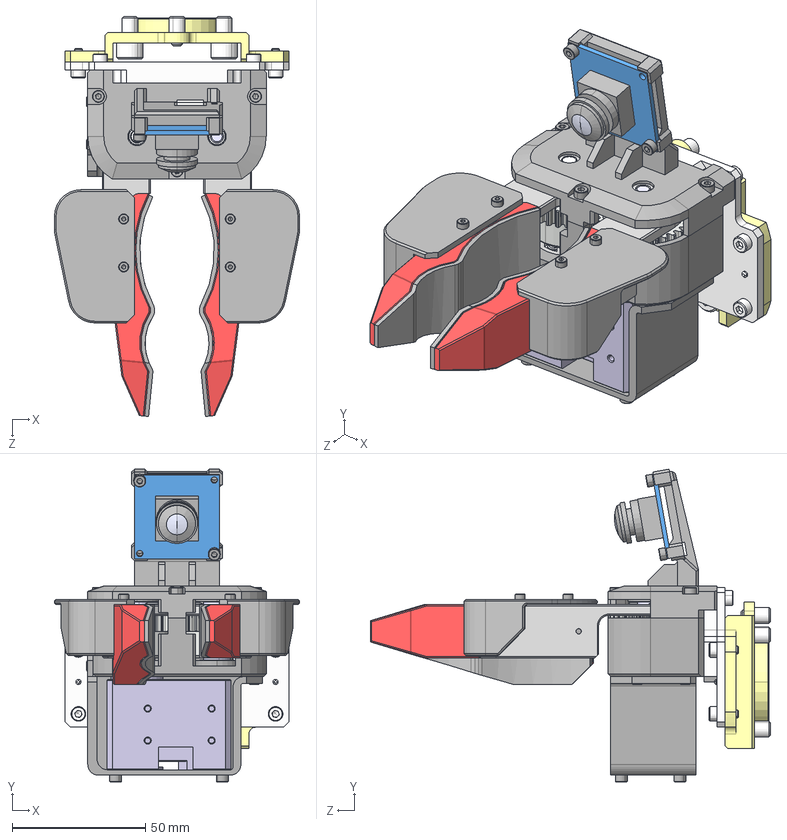
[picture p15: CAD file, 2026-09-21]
STEP/gripper/YUBI Gripper Assy_Dynamixel_ver2.STEP
92.0 x 117.4 x 150.1 mm
BRACKET_DYNAMIXEL
DYNAMIXEL XM430-W350-R
GEAR SHAFT
CASE
MTA05-13ZZ DBS x 3
WSSAB10-5-1 x 3
SSFRHQ8-20-F6-P5-T6-Q5-KC8-A12
GEAKB1.0-30-6-B-8N-QFC17-M3-LL x 2
FINGER ATTACHMENT_R
FINGER ATTACHMENT_L
PAD_t30_R
PAD_t20
RUBBER SHEET_t30_R
RUBBER SHEET_t20
UPPER PLATE_CAMERA BKT
USB CAMERA_ELP-USBFHD01M-L180
FLAP_R
FLAP_L
SB-304550 x 4
SB-264040 x 3
SB-203030 x 4
JPBPB2-3 x 2
JPDPB2-3 x 2
CB2.5-15 x 7
CB2.5-10 x 4
CB2.5-6 x 2
CB2-6 x 4
CBSTNR2-5 x 8
CBSTNR2.5-6
KEG3-8 x 2
CBSTNR3-8 x 4
CBE3-8 x 8
BRACKET_GRIPPER
UR5e_FLANGE
XDSHC6-P4-L6-B5
CBE6-10 x 4

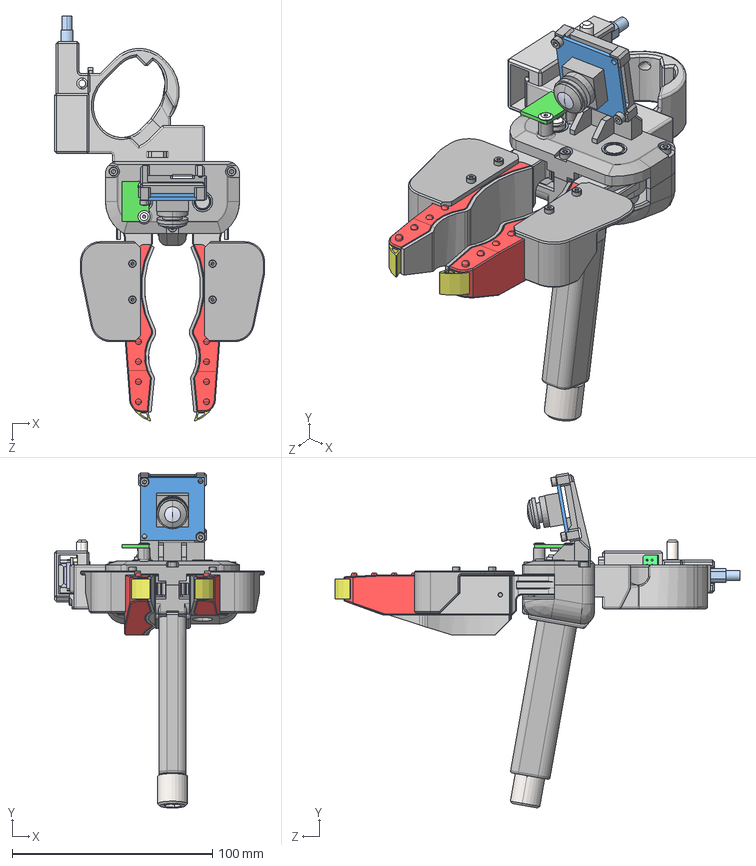
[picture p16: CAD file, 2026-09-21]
STEP/glove/YUBI Glove Assy_ver2_R_opt2.STEP
105.0 x 167.3 x 202.3 mm
UNDER PLATE_v2_INSERT TYPE
UPPER PLATE_CAMERA BKT_12bit_AS5601_v2_INSERT TYPE
FINGER ATTACHMENT_Glove_R_フック位置変更
FINGER ATTACHMENT_Glove_L_フック位置変更
CB2.5-10 x 4
PAD_t30_R_v2
PAD_t20_L_v2
Fin_v1 x 2
RUBBER SHEET_t30_v2_R
RUBBER SHEET_t20_v2_L
AS5601
HNTT5-5
GRIP
AJKTNS5-70
USB CAMERA_ELP-USBFHD01M-L180
CBSTNR3-5 x 2
MAGNET_D6_AS5601
FLAP_R
FLAP_L
HOLDER_Quest_45deg_R_INSERT TYPE
COVER1_R
COVER2_R
ESP32
UNIVERSAL PCB
CB2.5-15 x 3
CB2.5-6 x 4
CB3-6
LRLM3-6
CB2-6 x 4
JZF8-5 x 4
SB-264040 x 5
SB-304540 x 2

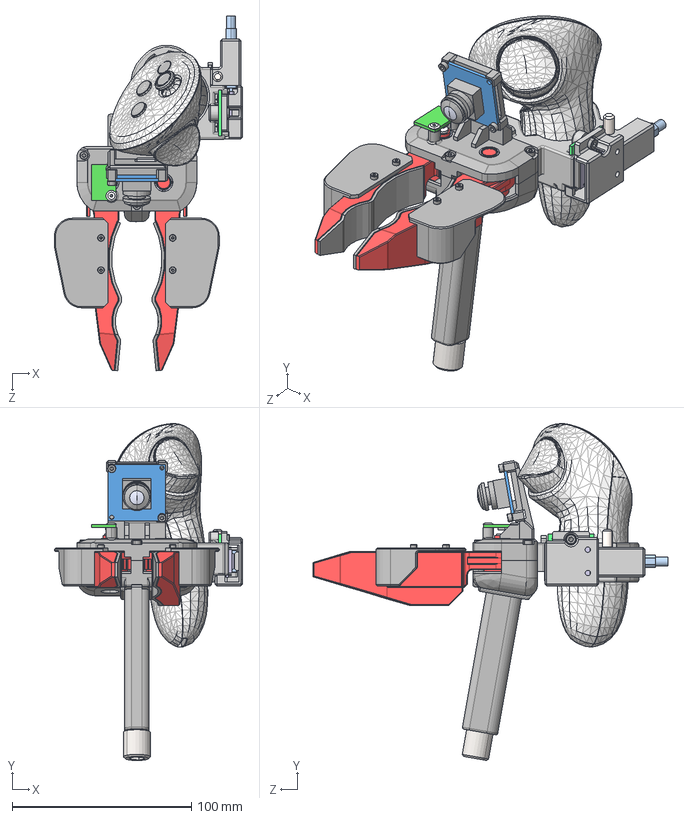
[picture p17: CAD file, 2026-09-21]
STEP/glove/YUBI Glove Assy_ver2_L.STEP
105.0 x 188.0 x 197.8 mm
UNDER PLATE_v2_INSERT TYPE
UPPER PLATE_CAMERA BKT_12bit_AS5601_v2_INSERT TYPE
RUBBER SHEET_t20
RUBBER SHEET_t30_L
AS5601
HNTT5-5
GRIP
AJKTNS5-70
USB CAMERA_ELP-USBFHD01M-L180
CBSTNR3-5 x 2
MAGNET_D6_AS5601
FLAP_R
FLAP_L
HOLDER_Quest_45deg_L_INSERT TYPE
COVER1_L
COVER2_L
ESP32
UNIVERSAL PCB
CB2.5-15 x 3
CB2.5-8 x 2
CB3-6
LRLM3-6
CB2-6 x 4
MetaQuestTouchPlus_Left
FINGER with Gear_Glove_t20_R_SHAFT DIA Φ8
FINGER with Gear_Glove_t30_L_SHAFT DIA Φ8
JZF8-5 x 4
SB-264040 x 5
SB-304540 x 2
CB2.5-6 x 2

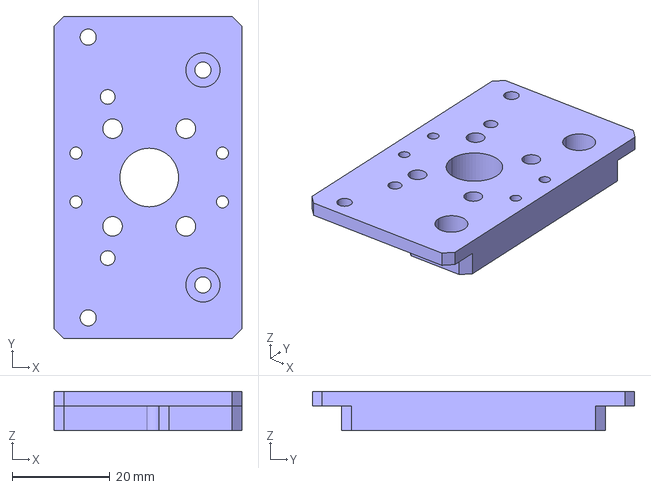
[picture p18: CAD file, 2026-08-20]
STEP/flange/UNITREE_G1_FLANGE.STEP
38.5 x 66.0 x 8.00 mm

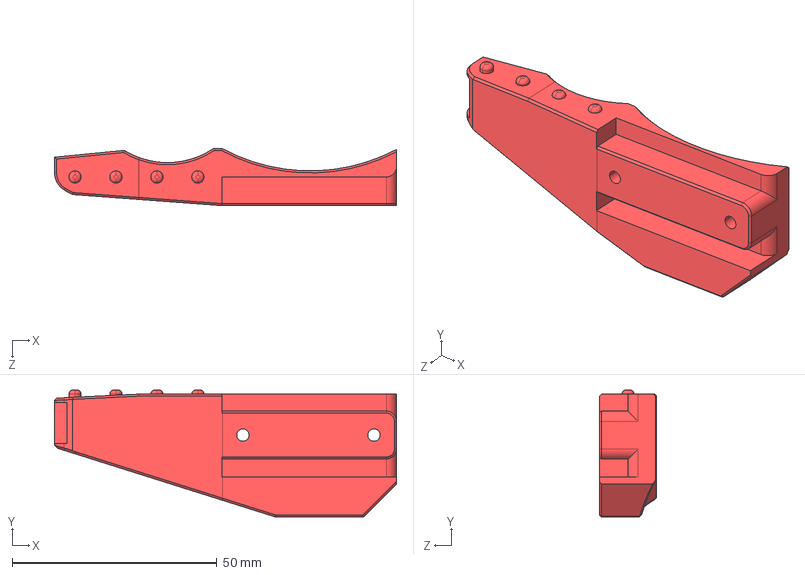
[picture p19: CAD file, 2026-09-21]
STEP/glove/option parts/FINGER PAD_t30_L_v2.STEP
83.5 x 31.0 x 14.0 mm

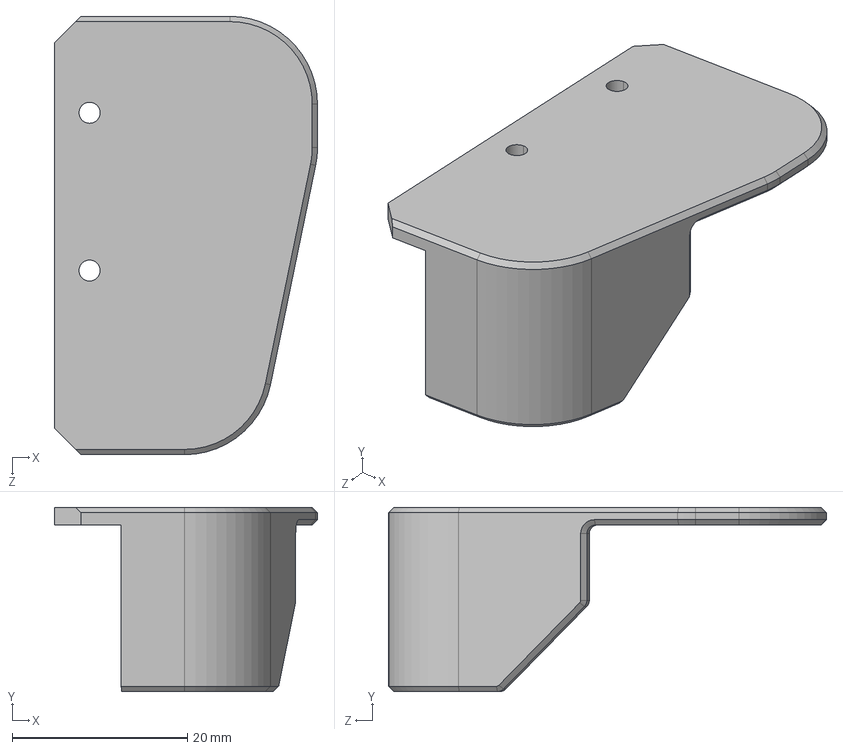
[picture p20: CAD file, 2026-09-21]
STEP/gripper/FLAP_L.STEP
30.0 x 21.0 x 50.0 mm

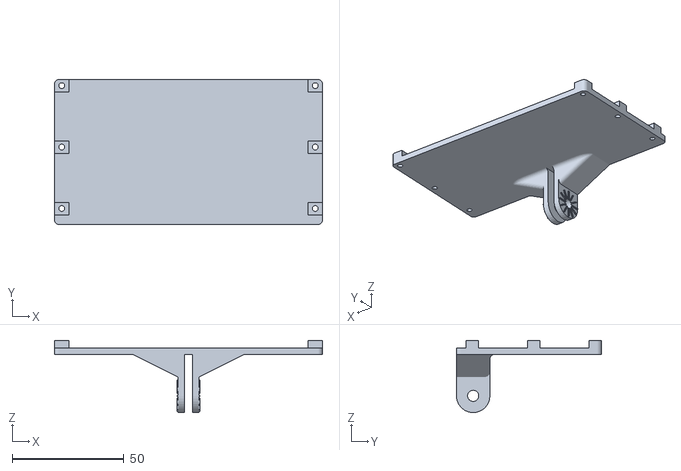
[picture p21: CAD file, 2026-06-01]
STL/portable/Display_plate.stl
120.0 x 65.0 x 32.3

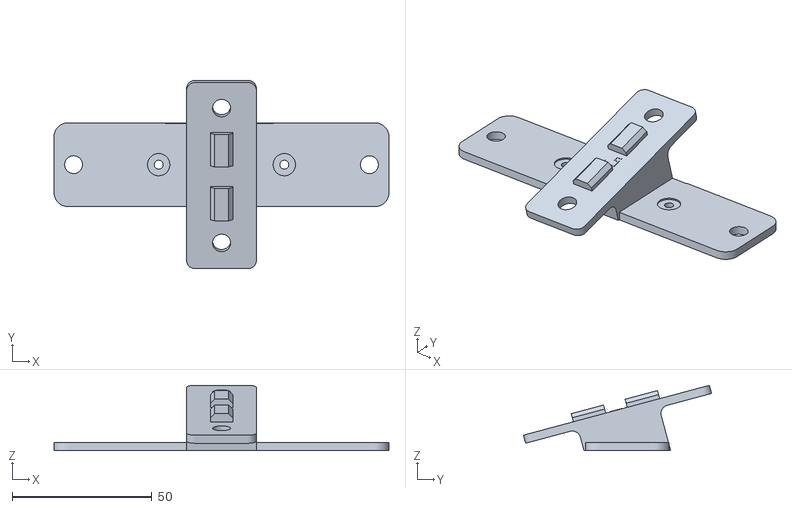
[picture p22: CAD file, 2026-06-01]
STL/stationary/realsense435_mount.stl
120.0 x 67.4 x 23.4

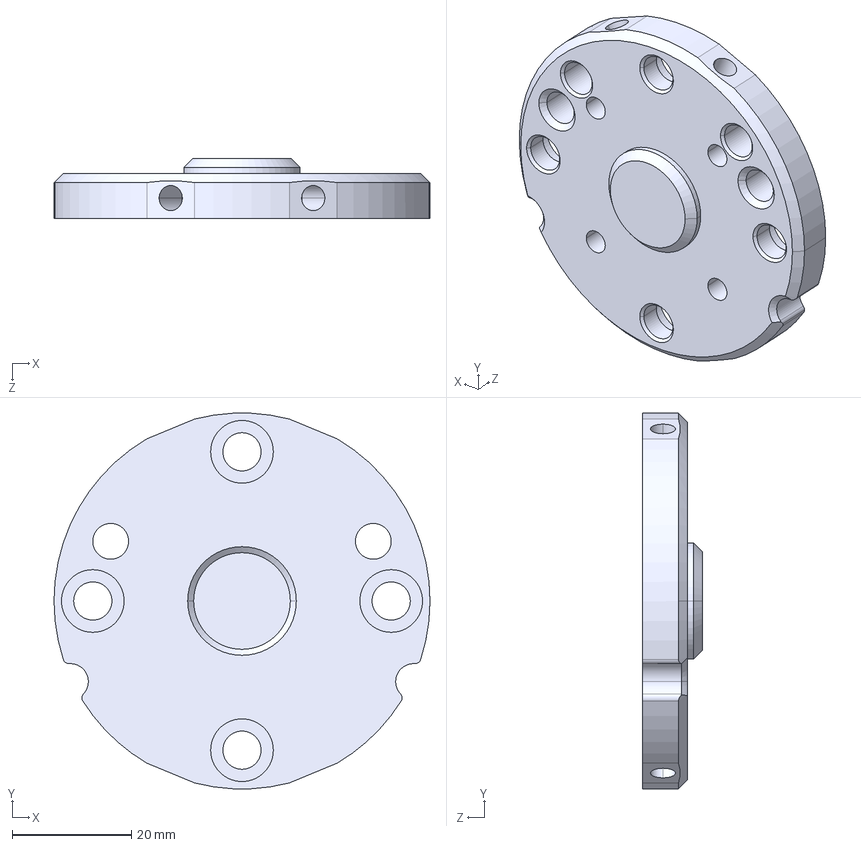
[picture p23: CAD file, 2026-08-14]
STEP/flange/OPENARM_FLANGE.STEP
63.0 x 62.9 x 10.0 mm

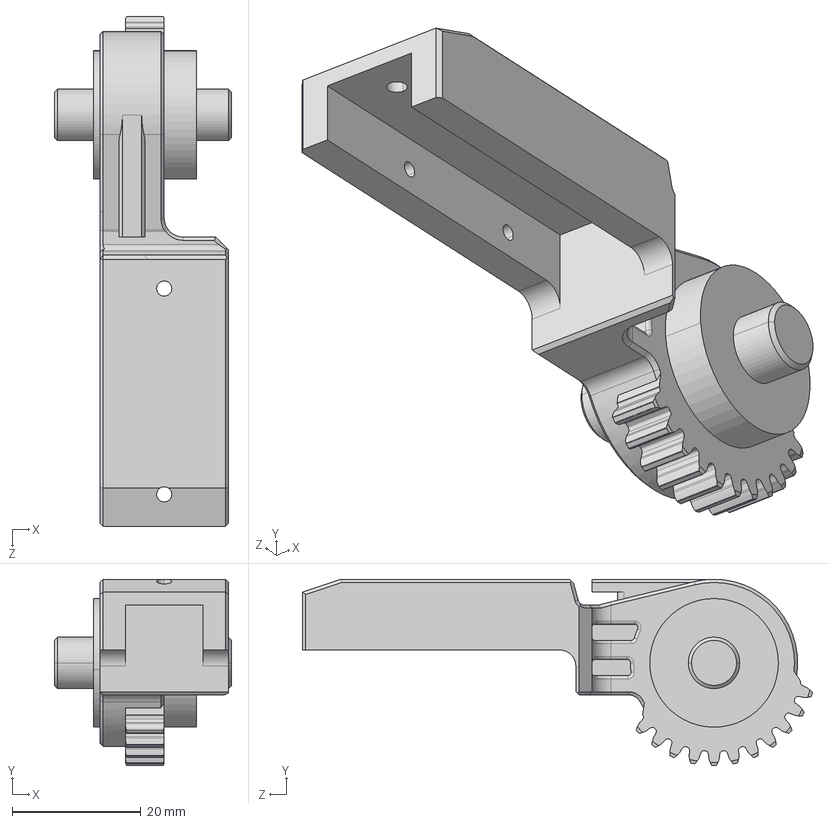
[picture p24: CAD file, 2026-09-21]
STEP/glove/option parts/FINGER ATTACHMENT_Glove_L.STEP
27.6 x 29.0 x 79.3 mm

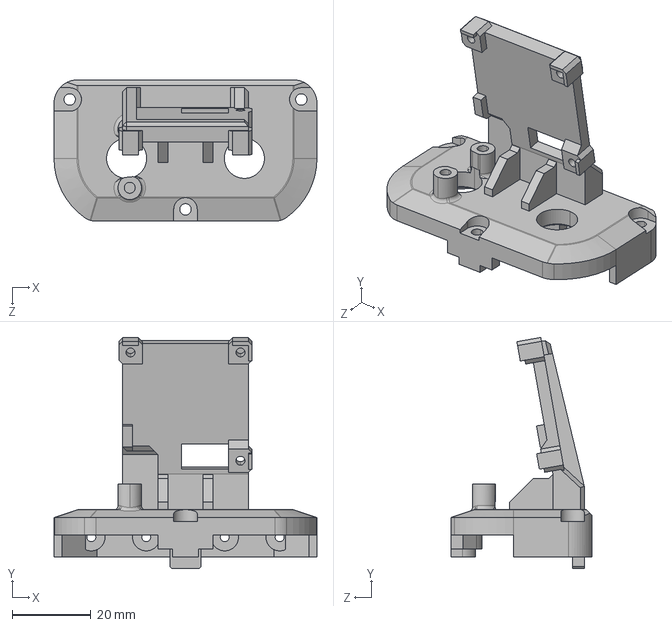
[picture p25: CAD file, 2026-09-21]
STEP/glove/UPPER PLATE_CAMERA BKT.STEP
67.0 x 58.9 x 36.0 mm

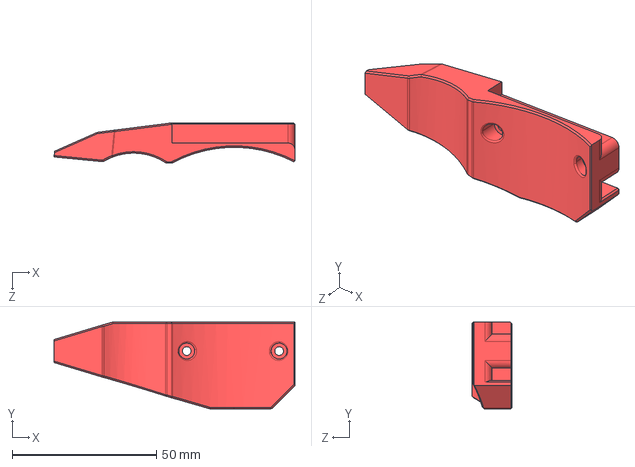
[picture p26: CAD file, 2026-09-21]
STEP/gripper/FINGER PAD_t30_R.STEP
83.5 x 30.0 x 14.0 mm

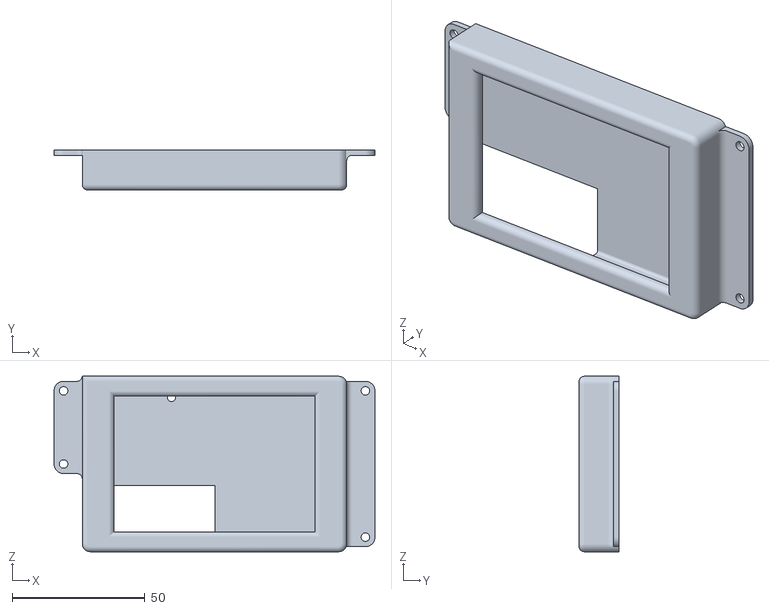
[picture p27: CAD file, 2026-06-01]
STL/portable/Display_case.stl
120.7 x 15.0 x 66.0

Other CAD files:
STEP/glove/YUBI Glove Assy_ver2_R_opt1.STEP
STL/stationary/Quest_mount.stl
STEP/flange/FRANKA_FLANGE.STEP
STEP/flange/YUBI_ATTACHMENT.STEP
STEP/glove/COVER_CABLE_L.STEP
STEP/glove/COVER_CABLE_R.STEP
STEP/glove/COVER_PCB_L.STEP
STEP/glove/COVER_PCB_R.STEP
STEP/glove/FINGER with Gear_t20_L.STEP
STEP/glove/FINGER with Gear_t20_R.STEP
STEP/glove/FINGER with Gear_t30_L.STEP
STEP/glove/FINGER with Gear_t30_R.STEP
STEP/glove/FLAP_R.STEP
STEP/glove/GRIP.STEP
STEP/glove/HOLDER_Quest_L.STEP
STEP/glove/HOLDER_Quest_R.STEP
STEP/glove/UNDER PLATE_v2.STEP
STEP/glove/option parts/FINGER ATTACHMENT_Glove_R.STEP
STEP/glove/option parts/FINGER PAD_t20.STEP
STEP/glove/option parts/FINGER PAD_t20_L_v2.STEP
STEP/glove/option parts/FINGER PAD_t20_R_v2.STEP
STEP/glove/option parts/FINGER PAD_t30_L.STEP
STEP/glove/option parts/FINGER PAD_t30_R_v2.STEP
STEP/glove/option parts/Fin.STEP
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

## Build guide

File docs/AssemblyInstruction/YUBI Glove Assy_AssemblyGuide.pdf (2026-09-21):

YUBI Glove Assy_ver.2 Assembly Procedure

【Assembly Procedure】
(1) Install components onto UPPER PLATE
- Install INSERTs
- Install BUSHINGs
(2) Install components onto UNDER PLATE
- Install INSERTs
- Install BUSHINGs
(3) Install components onto FINGER with Gear_t30_R or t20_R
- Install RUBBER SHEET
- Install ENCODER MAGNET
(4) Install components onto FINGER with Gear_t30_L or t20_L
- Install RUBBER SHEET
(5) Install FINGER with Gear and UPPER PLATE
(6) Install FLAPs | 【YUBI Glove Assy_ver.2_for Right-hand】
- Install FLAP_R
- Install FLAP_L
(7) Install HOLDER_Quest_R/L
- Install INSERTs
- Install HOLDER_Quest_R/L
(8) Install PCB and Wiring
- Install PCB (AS5601) onto UPPER PLATE
- Install PCB (ESP32C6) on HOLDER_Quest_R/L
- Install USB TYPE-C CABLE
(9) Install CAMERA
- Install CAMERA
- Connect CAMERA WIRING

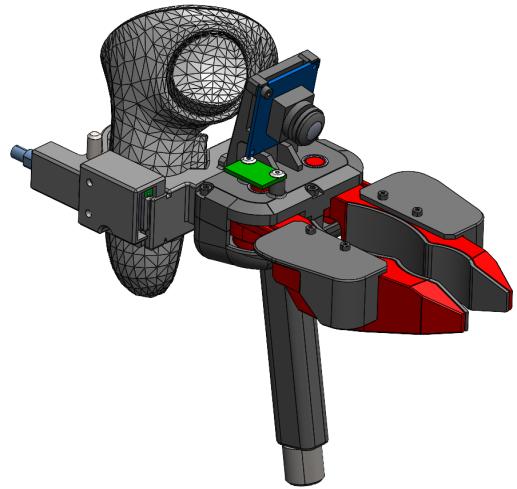
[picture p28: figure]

(10) Install GRIP | 【YUBI Glove Assy_ver.2_for Left-Hand】
- Install T-SLOT NUT
- Install GRIP
- Adjust GRIP position
(11) Install Rubber Band for Finger opening and closing
(12) Install Meta Quest Touch Plus Controller

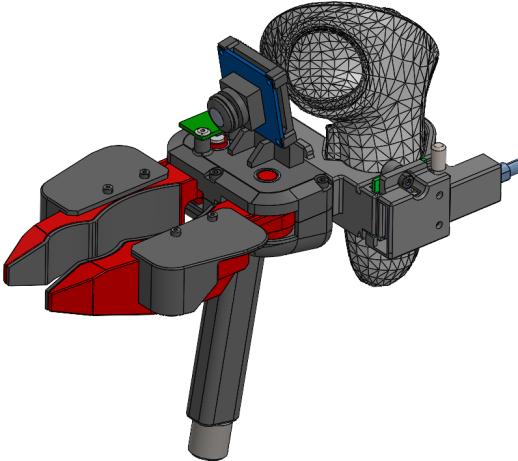
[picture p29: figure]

【Optional Parts Assembly Procedure】
(1) Install FINGER ATTACHMENT_Glove and FINGER PAD

(1) Install components onto UPPER PLATE
- Install INSERTs
Install following INSERTs into UPPER PLATE
① SB-264040: 2 pcs. (Installation positions differ between for right-hand and left-hand versions.)
【for Right-hand Version】 | 【for Left-hand Version】

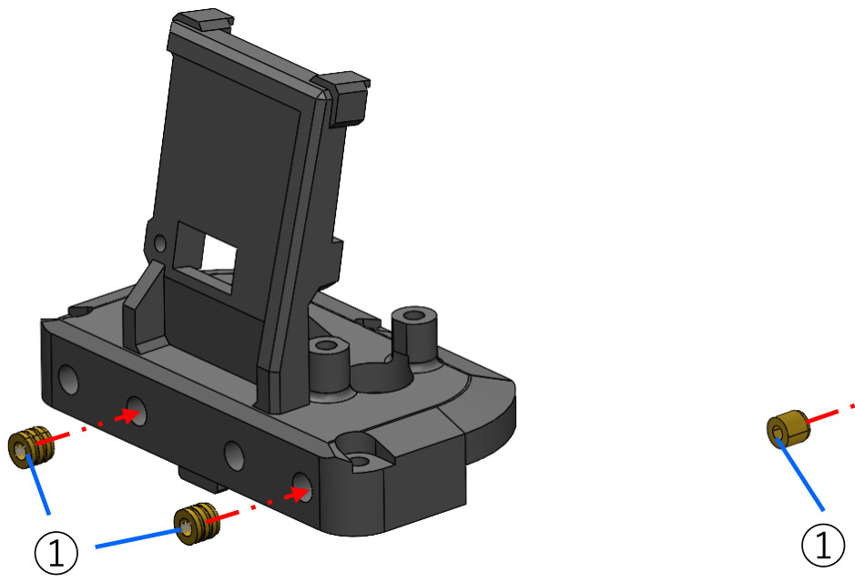
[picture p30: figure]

- Install BUSHINGs
Install following BUSHINGs into UPPER PLATE ② JZF8-5: 2 pcs.

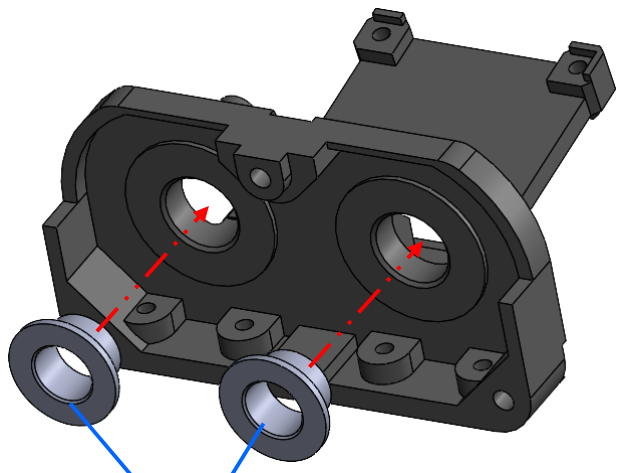
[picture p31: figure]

②

(2) Install components onto UNDER PLATE
- Install INSERTs
Install following INSERTs into UNDER PLATE

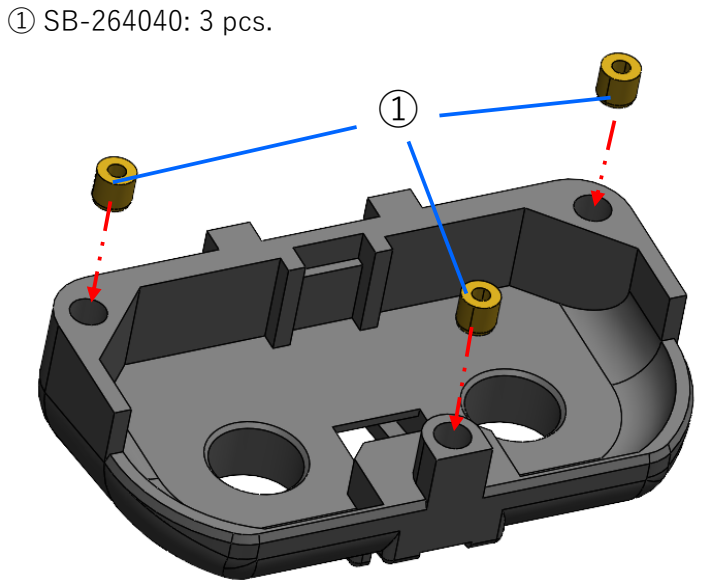
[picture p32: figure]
① SB-264040: 3 pcs.

- Install BUSHINGs
Install following BUSHINGs into UNDER PLATE

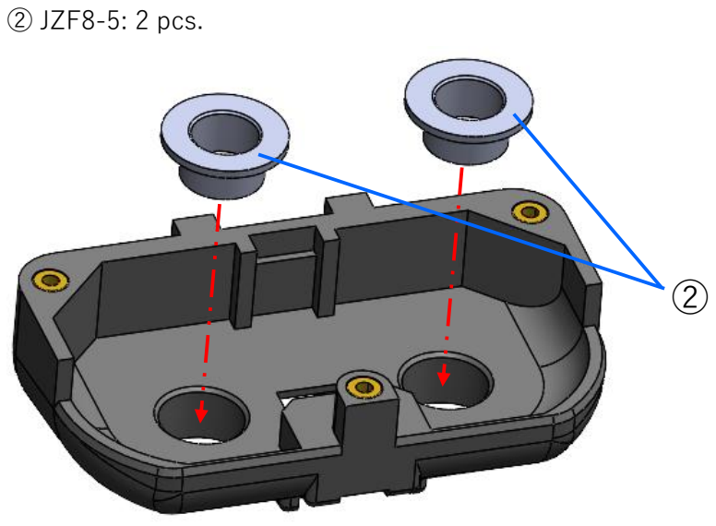
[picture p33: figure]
② JZF8-5: 2 pcs.

(3) Install components onto FINGER with Gear_t30_R or t20_R
- Install RUBBER SHEET
① Attach RUBBER SHEET onto FINGER with Gear_t30_R or t20_R using adhesive (e.g., Super X).
Select RUBBER SHEET size based on gripping location and required area.

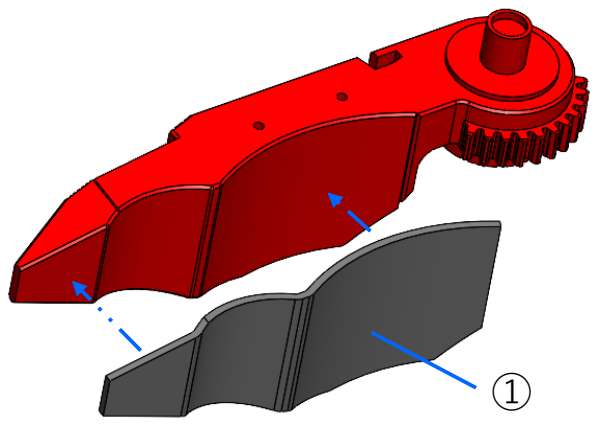
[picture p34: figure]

- Install ENCODER MAGNET
② Attach NEODYMIUM MAGNET_AS5601 to FINGER with Gear_t30_R or t20_R using instant adhesive.

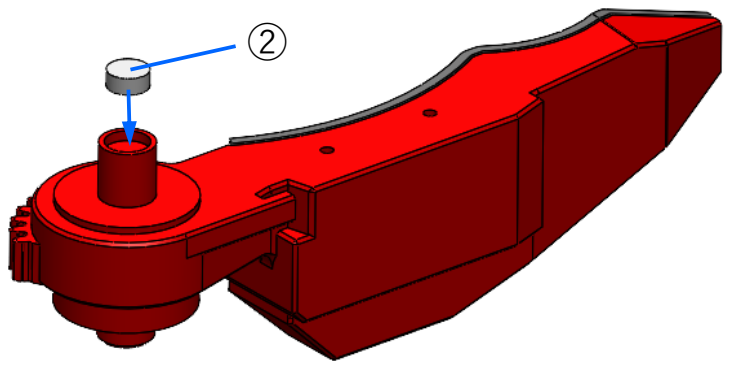
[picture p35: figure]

(4) Install components onto FINGER with Gear_t30_L or t20_L
- Install RUBBER SHEET
① Attach RUBBER SHEET to FINGER with Gear_t30_L or t20_L using adhesive (e.g., Super X).
Select RUBBER SHEET size based on gripping location and required area.

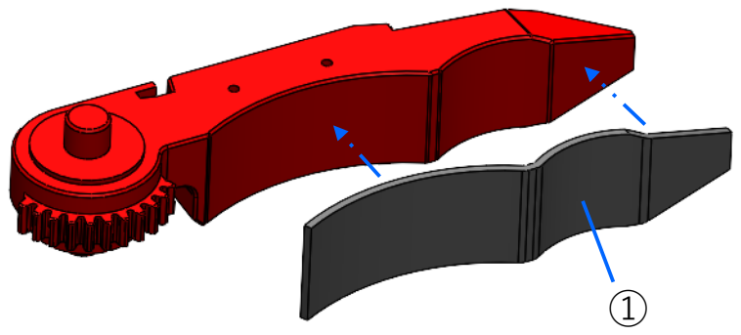
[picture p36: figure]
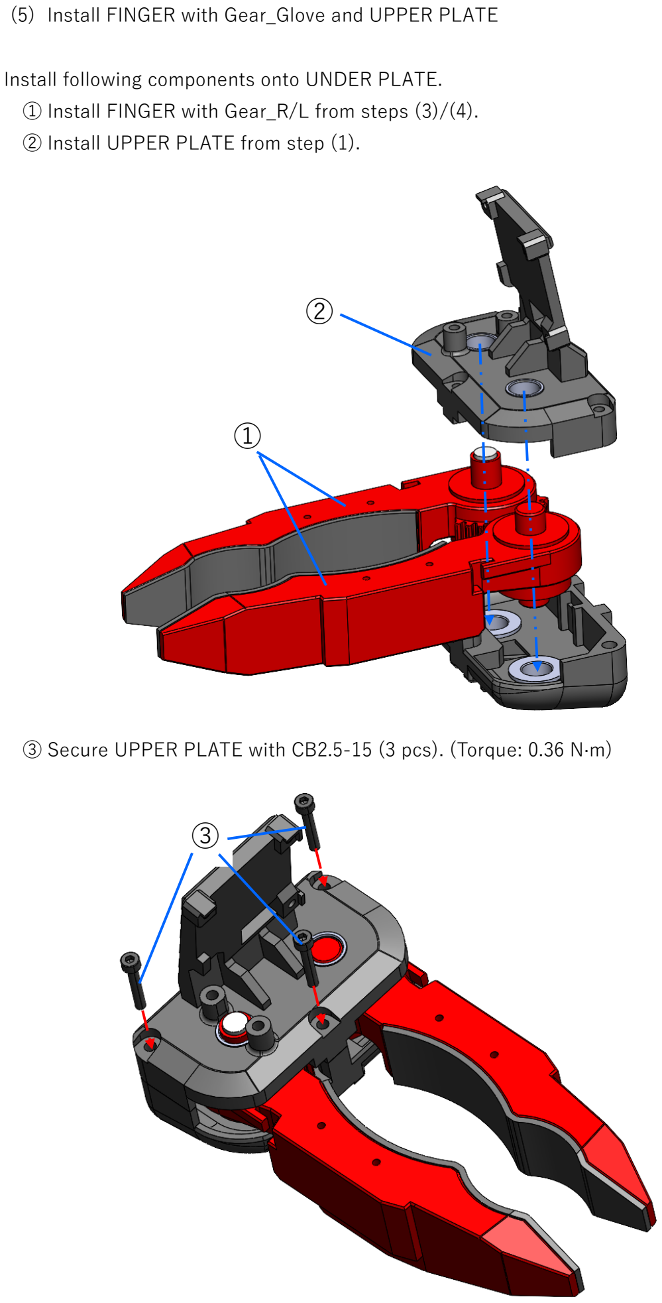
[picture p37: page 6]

(5) Install FINGER with Gear_Glove and UPPER PLATE

Install following components onto UNDER PLATE.
① Install FINGER with Gear_R/L from steps (3)/(4). ② Install UPPER PLATE from step (1).

③ Secure UPPER PLATE with CB2.5-15 (3 pcs). (Torque: 0.36 N·m)

②

③

①

(6) Install FLAPs
- Install FLAP_R
① Install FLAP_R on FINGER with Gear_t30_R or t20_R. ② Secure FLAP_R with CB2-6 (2 pcs). (Torque: 0.315 N·m)

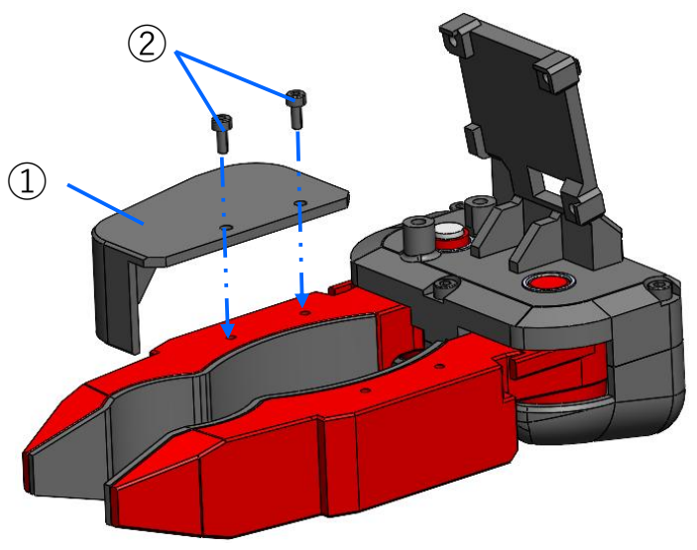
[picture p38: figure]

- Install FLAP_L
③ Install FLAP_L onto FINGER with Gear_t30_L or t20_L. ④ Secure FLAP_L with CB2-6 (2 pcs). (Torque: 0.315 N·m)

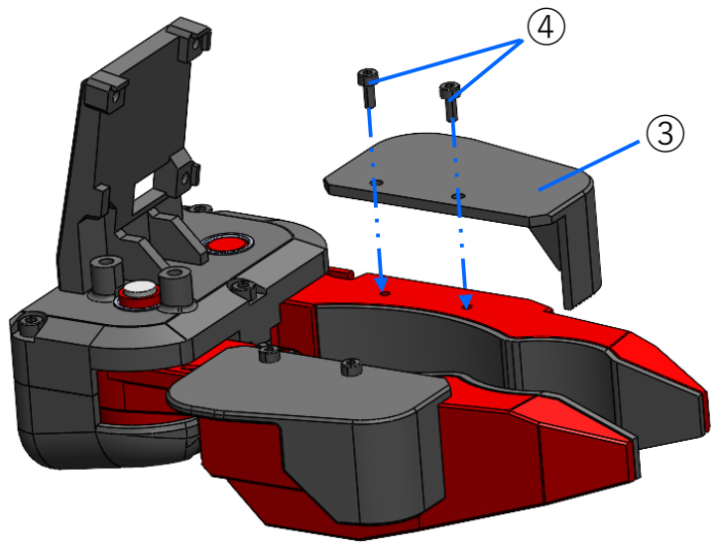
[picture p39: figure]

(7) Install HOLDER_Quest_R/L
- Install INSERTs
Install following INSERTs in HOLDER_Quest_R/L. ① SB-304540: 2 pcs.

【for Right-hand Version】
- Install HOLDER_Quest_R
② Install HOLDER_Quest_R onto rear side of UPPER PLATE. (Press it against locating features.) ③ Secure HOLDER_Quest_R with CB2.5-8 (2 pcs). (Torque: 0.36 N·m)

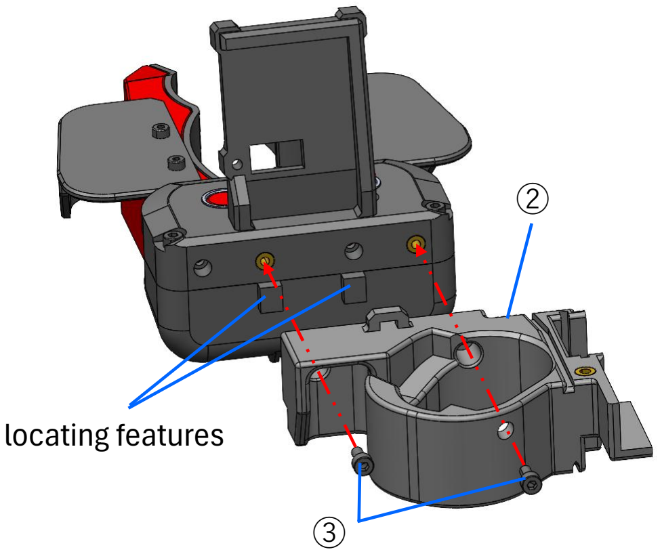
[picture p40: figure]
locating features

【for Left-hand Version】
- Install HOLDER_Quest_L
④ Install HOLDER_Quest_L onto rear side of UPPER PLATE. (Press it against locating features.) ⑤ Secure HOLDER_Quest_L with CB2.5-8 (2 pcs). (Torque: 0.36 N·m)

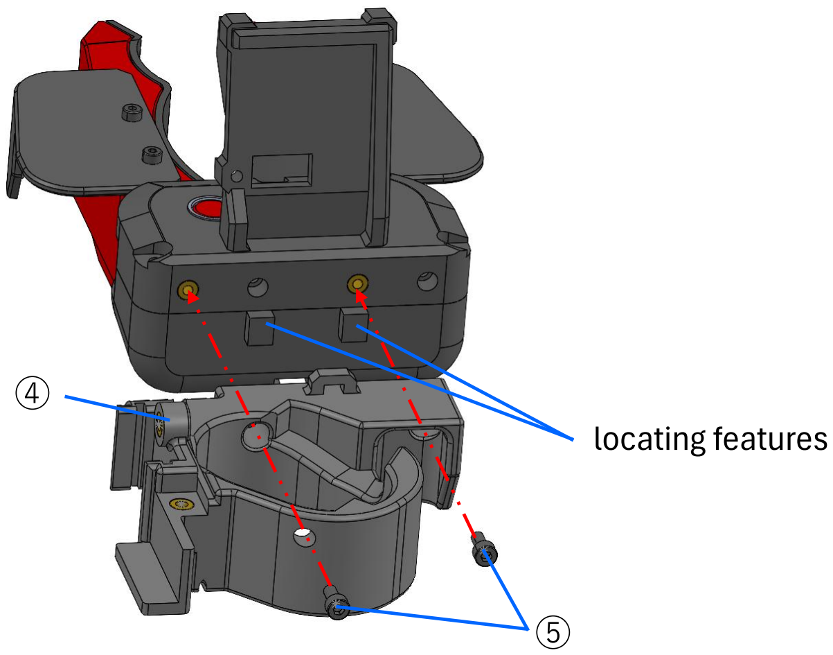
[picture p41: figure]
locating features

(8) Install wiring onto PCB
- Install wiring onto PCB following procedure below

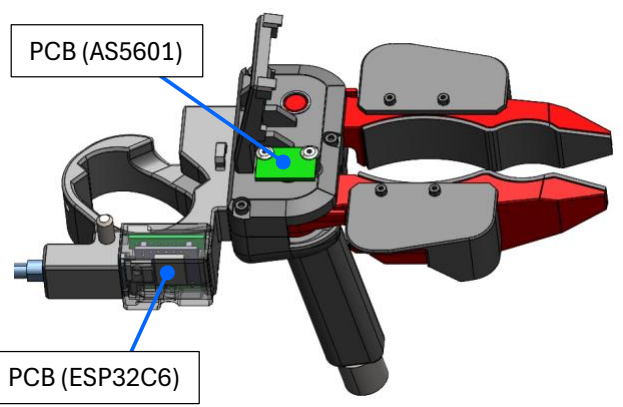
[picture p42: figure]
PCB (ESP32C6); PCB (AS5601)

① Solder wires onto PCB (ESP32C6) and PCB (AS5601). Refer to connection table for wiring positions (see figure).

PCB(ESP32C6)

PCB(AS5601) | Connection Table
ESP32C6 | Wire Type / Color | AS5601
3V3 | AWG28 / Black | 3V3
GND | AWG28 / Black | GND
D4 | AWG28 / Black | SDA
D5 | AWG28 / Black | SCL

Wire Length for Right-hand Version: 80 mm for Left-hand Version: 180 mm

② Secure PCB (ESP32C6) onto UNIVERSAL PCB (25.4 × 25.4 × t1.6) using PIN HEADERs.

Fix at same position for right-hand and left-hand versions

③ Assemble COVER_PCB_R/L onto PCB (ESP32C6) + UNIVERSAL PCB assembly from step ②.
- Hook COVER_PCB_R/L from side of PCB and place it.
Route wires from front side.
Front side | Front side
Installed State | Installed State
(for Right-hand Version) | (for Left-hand Version)

④ Assemble COVER_PCB_R/L with PCB into groove of Quest HOLDER_R/L by hooking UNIVERSAL PCB and sliding from top.

⑤ Secure COVER_PCB_R/L with CB3-6 (1 pc). (Torque: 0.63 N・m)

groove of Quest HOLDER

⑤

COVER_PCB_R

COVER_PCB_R

⑥ Connect USB cable to PCB (ESP32C6).

⑦ Install COVER_CABLE_R/L on Quest HOLDER_R/L and secure it with LRLM3-6 bolt.

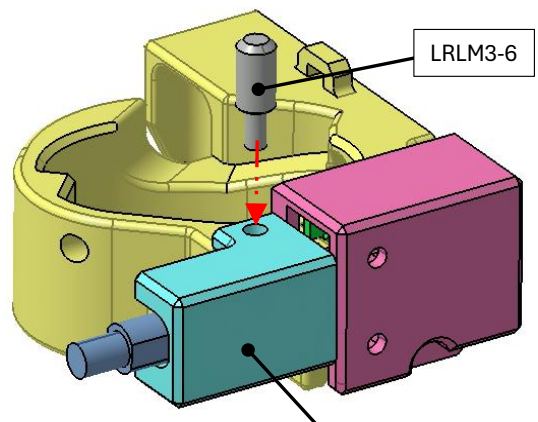
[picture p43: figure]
LRLM3-6

⑧ Install PCB (AS5601) onto UPPER PLATE with CBSTNR3-5 (2 pcs). (Torque: 0.63 N·m)

COVER_CABLE_R

⑨ If excess wiring remains, secure wires to hook section of Quest HOLDER_R/L using cable ties.

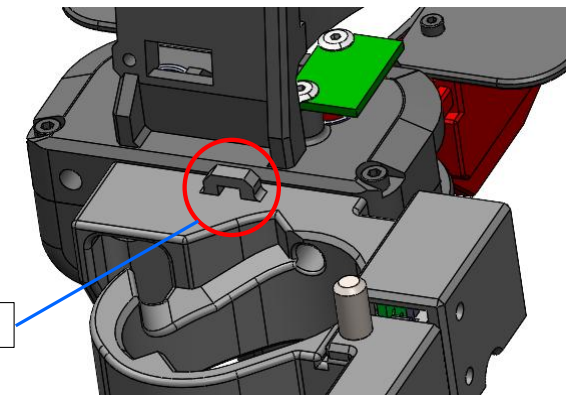
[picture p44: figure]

【PCB + Cover Assembly State】

Hook

(9) Install CAMERA
- Install CAMERA
① Place CAMERA on CAMERA_BRACKET of UPPER PLATE. ② Secure CAMERA with CB2.5-6 (2 pcs). (Torque: 0.36 N·m)

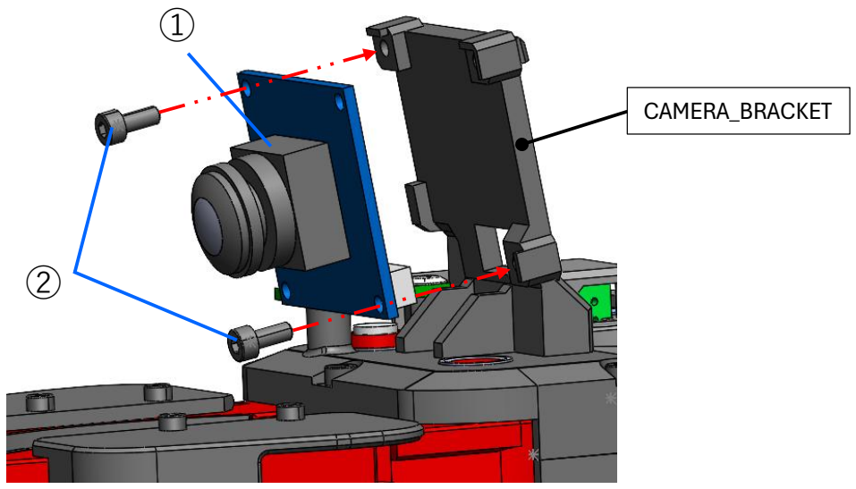
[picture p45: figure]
CAMERA_BRACKET

- Connect CAMERA WIRING
③ Connect CAMERA WIRING to connector from rear side of CAMERA_BRACKET.

(10) Install GRIP
- Install T-SLOT NUT
① Install T-SLOT NUT in the groove of UNDER PLATE.

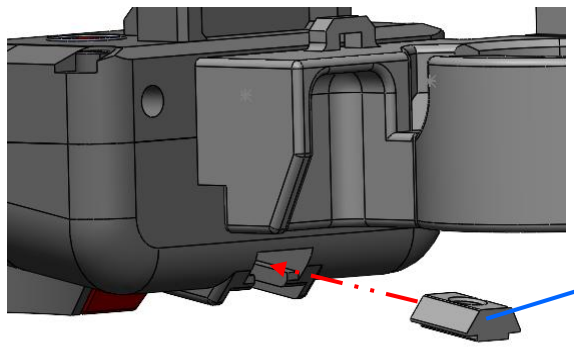
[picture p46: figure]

- Install GRIP
② Install GRIP by passing ADJUST BOLT through GRIP.

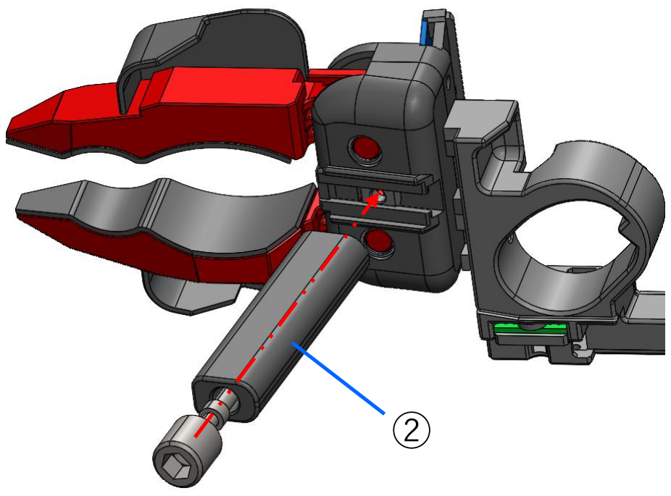
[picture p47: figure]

- Adjust GRIP position
③ Slide the GRIP forward or backward to a comfortable position. ④ Hand-tighten the ADJUST BOLT to secure the GRIP.

①

(11) Install Rubber Band for Finger Opening and Closing
- Install rubber band No.16 for finger opening and closing as follows.
① Hook rubber band No.16 onto the hook at base of the finger.
Use right-finger side for right-hand version and left-finger side for left-hand Version. ② Hook rubber band onto the hook and groove of HOLDER_Quest_R/L.
③ Confirm that the fingers open and close smoothly.

(12) Install Meta Quest Touch Plus Controller

① Remove battery cover from Meta Quest Touch Plus Controller_R/L.
② Install Meta Quest Touch Plus Controller_R/L in HOLDER_Quest_R/L.
Install it so that the switch on the side of Meta Quest Touch Plus Controller_R/L rests on the notch of HOLDER_Quest_R/L.

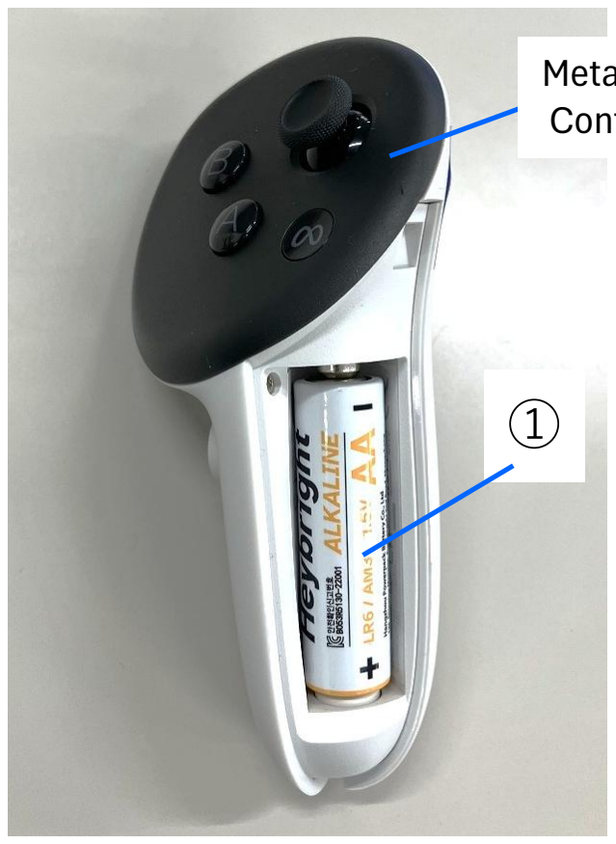
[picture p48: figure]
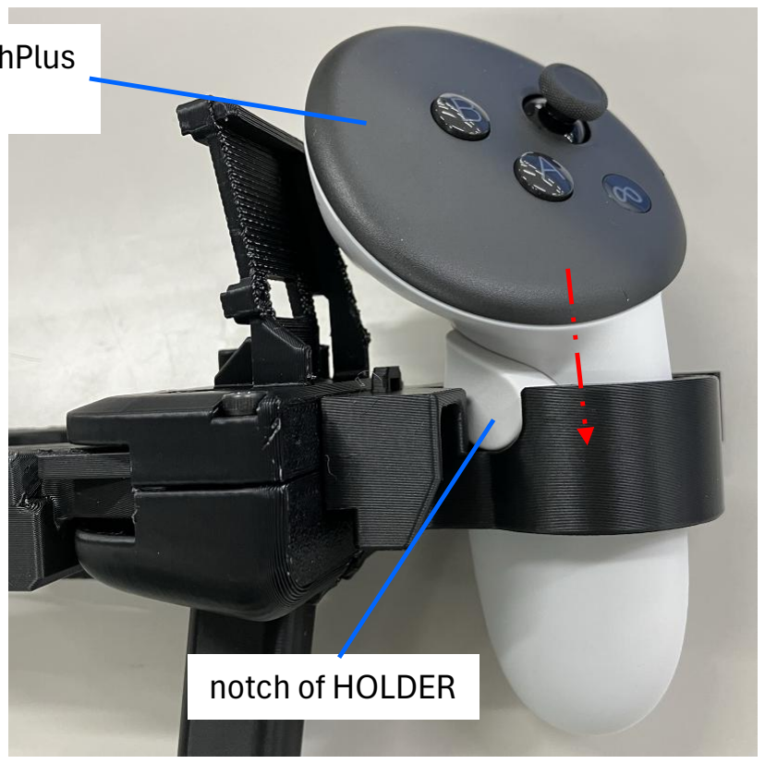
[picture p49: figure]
notch of HOLDER

## MetaQuestTouchPlus Controller_R

【Optional Parts Assembly Procedure】
(1) Install FINGER ATTACHMENT_Glove and FINGER PAD
- Install FINGER PAD

① Install FINGER PAD_t30_R/L or FINGER PAD_t20 on FINGER ATTACHMENT_Glove_R/L. When using FINGER PAD_R/L_v2, install Fin at the fingertip.
② Secure FINGER PAD with CB2.5-10 (2 pcs). (Torque: 0.36 N·m)

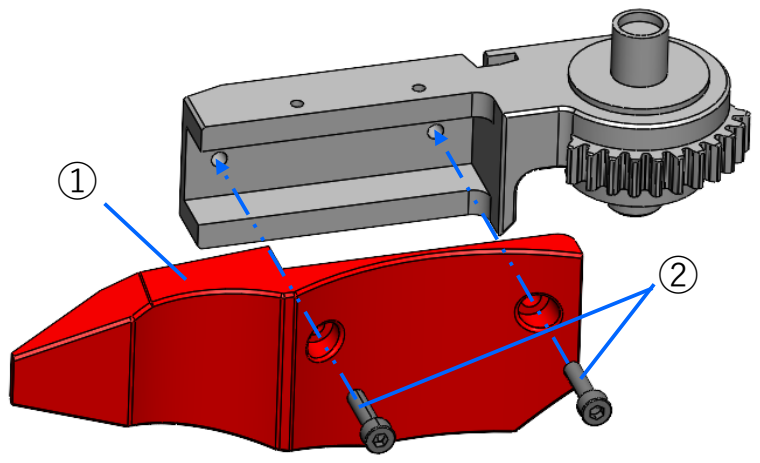
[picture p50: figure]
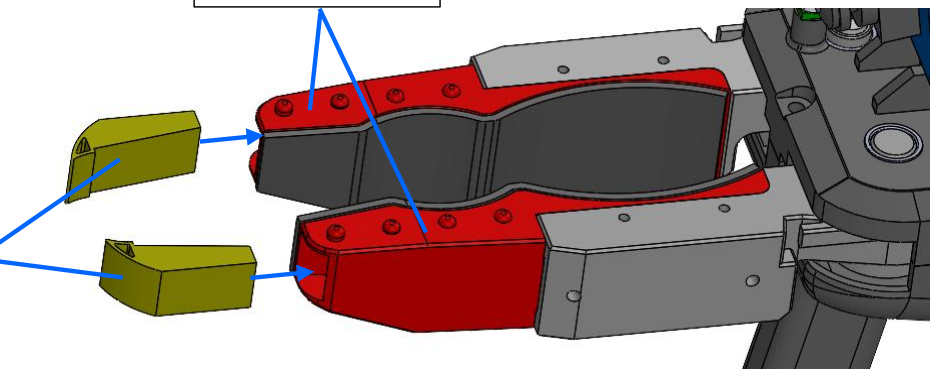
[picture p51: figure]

- Install RUBBER SHEET
③ Attach RUBBER SHEET onto FINGER PAD using adhesive (e.g., Super X). Select RUBBER SHEET size based on gripping location and required area.

### FIN

### FINGER PAD_v2

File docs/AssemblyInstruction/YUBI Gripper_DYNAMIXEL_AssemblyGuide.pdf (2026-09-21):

YUBI Gripper_DYNAMIXEL_ver.2 Assembly Procedure [Assembly State]
[Assembly Procedure]
(1) Installation of components onto UPPER PLATE
- Install inserts
- Install locating pins
(2) Installation of components onto CASE
- Install inserts
(3) Installation of components onto DYNAMIXEL
- Install supplied wheel
- Install GEAR SHAFT
(4) Installation of components onto FINGER ATTACHMENT_R
- Install FINGER PAD
- Install RUBBER SHEET
(5) Installation of components onto FINGER ATTACHMENT_L
- Install FINGER PAD
- Install RUBBER SHEET
(6) Installation of DYNAMIXEL
- Remove bottom bolts
- Install BRACKET_DYNAMIXEL
- Install CASE
(7) Installation of FINGER ASSY_R (Right Finger, Step (4))
- Install SPUR GEAR
- Install FINGER ASSY_R
(8) Installation of FINGER ASSY_L (Left Finger, Step (5))
- Install SPUR GEAR
- Install FINGER ASSY_L
(9) Installation of UPPER PLATE
- Install bearings
- Install UPPER PLATE
(10) Installation of FLAPs
- Install FLAP_R
- Install FLAP_L
(11) Installation of CAMERA
- Install CAMERA
(12) Installation of YUBI Gripper_DYNAMIXEL onto UR5e
- Install BRACKET_GRIPPER
- Install UR5e_FLANGE onto UR5e
- Install YUBI Gripper_DYNAMIXEL onto UR5e

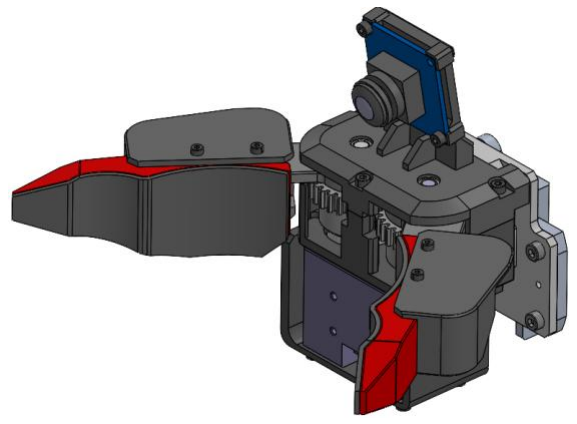
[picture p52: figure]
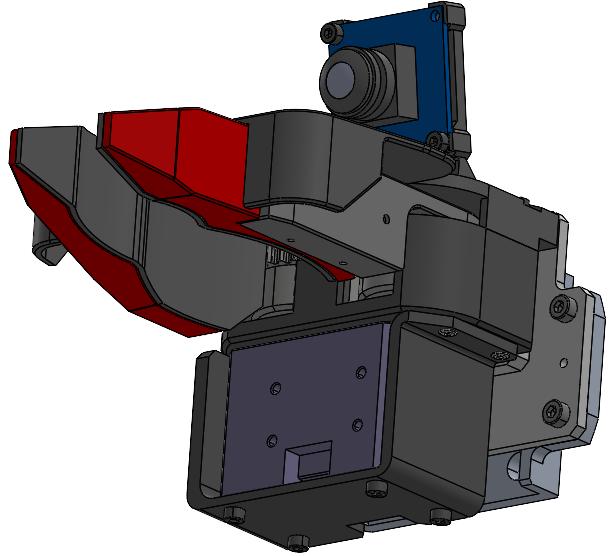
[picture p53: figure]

(1) Installation of components onto UPPER PLATE
- Install inserts
Install the following inserts into UPPER PLATE.
1) SB-304540: 2 pcs

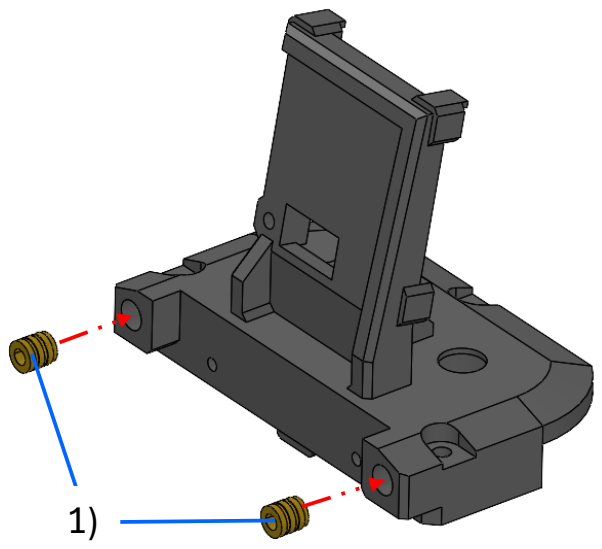
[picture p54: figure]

- Install locating pins
Install the following locating pins into UPPER PLATE.
2) JPBPB2-3: 1 pc
3) JPDPB2-3: 1 pc

2)

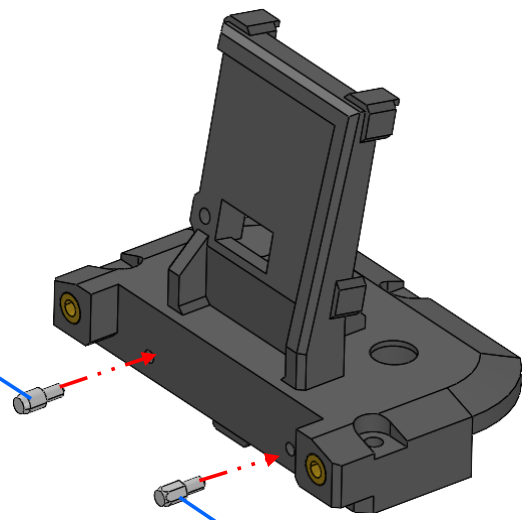
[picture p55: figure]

3)

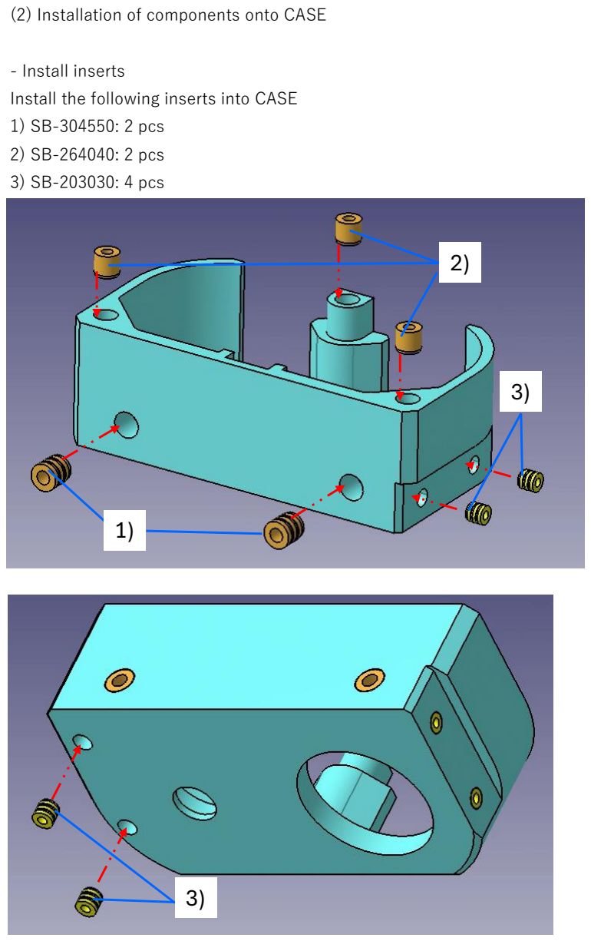
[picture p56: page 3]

(2) Installation of components onto CASE
- Install inserts
Install the following inserts into CASE
1) SB-304550: 2 pcs
2) SB-264040: 2 pcs
3) SB-203030: 4 pcs

2)

1)

3)

3)

1)

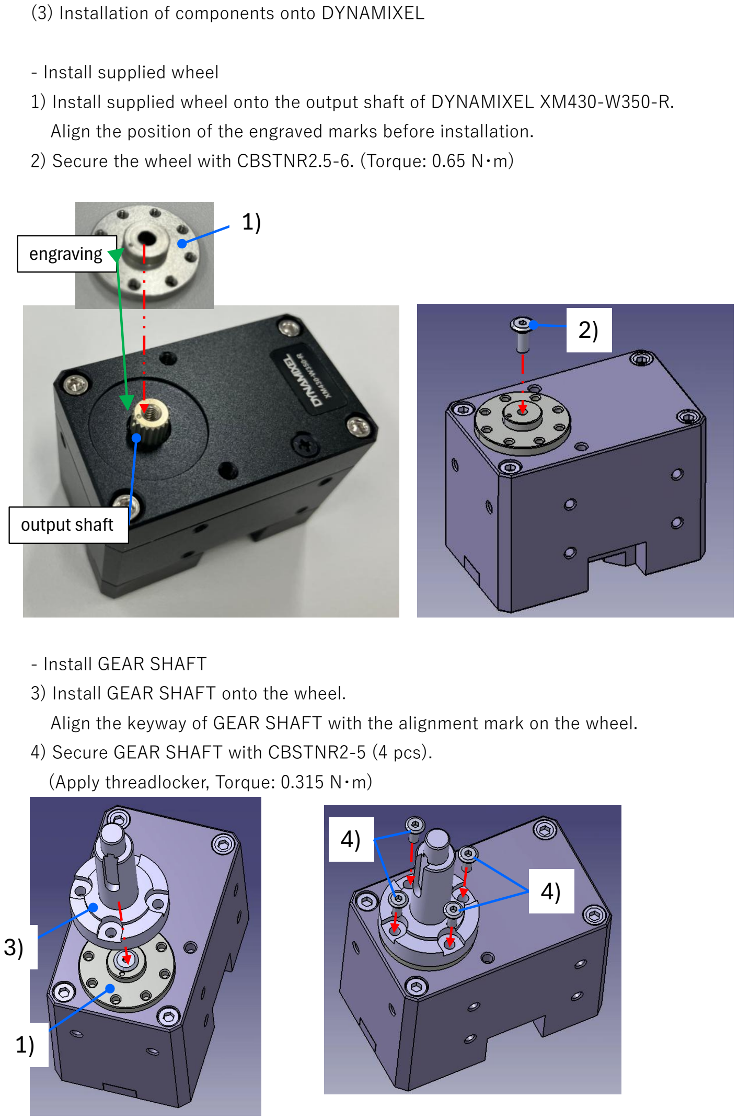
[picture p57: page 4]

(3) Installation of components onto DYNAMIXEL
- Install supplied wheel
1) Install supplied wheel onto the output shaft of DYNAMIXEL XM430-W350-R. Align the position of the engraved marks before installation.
2) Secure the wheel with CBSTNR2.5-6. (Torque: 0.65 N･m)
- Install GEAR SHAFT
3) Install GEAR SHAFT onto the wheel.
Align the keyway of GEAR SHAFT with the alignment mark on the wheel.
4) Secure GEAR SHAFT with CBSTNR2-5 (4 pcs).
(Apply threadlocker, Torque: 0.315 N･m)

## output shaft

## engraving

2)

1)

3)

4)

4)

(4) Installation of components onto FINGER ATTACHMENT_R
- Install FINGER PAD
1) Install FINGER PAD_t30_R or FINGER PAD_t20 onto FINGER ATTACHMENT_R.
2) Secure FINGER PAD with CB2.5-10 (2 pcs). (Torque: 0.36 N･m)

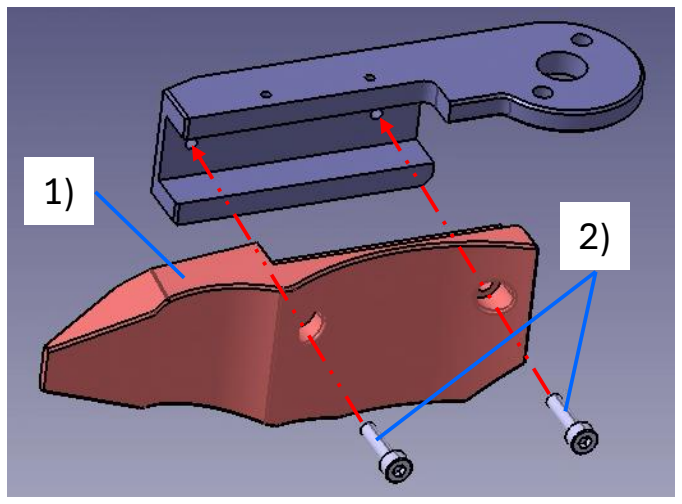
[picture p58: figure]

- Install RUBBER SHEET
3) Attach RUBBER SHEET to FINGER PAD using suitable adhesive.
The size of RUBBER SHEET may be selected based on the gripping location and required area.

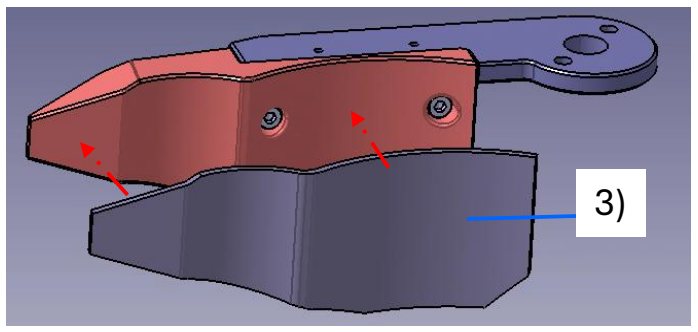
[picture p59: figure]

(5) Installation of components onto FINGER ATTACHMENT_L
- Install FINGER PAD
1) Install FINGER PAD_t30_L or FINGER PAD_t20 onto FINGER ATTACHMENT_L.
2) Secure FINGER PAD with CB2.5-10 (2 pcs). (Torque: 0.36 N･m)

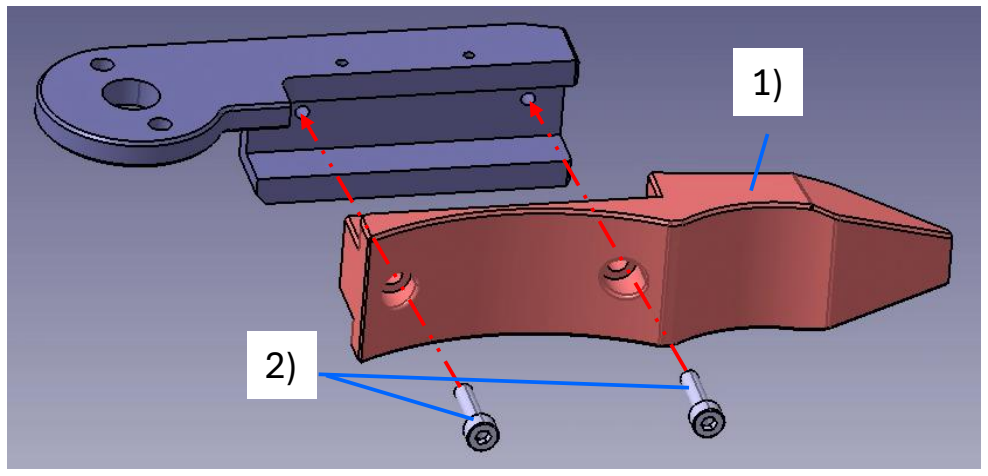
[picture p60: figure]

- Install RUBBER SHEET
3) Attach RUBBER SHEET to FINGER PAD using suitable adhesive.
The size of RUBBER SHEET may be selected based on the gripping location and required area.

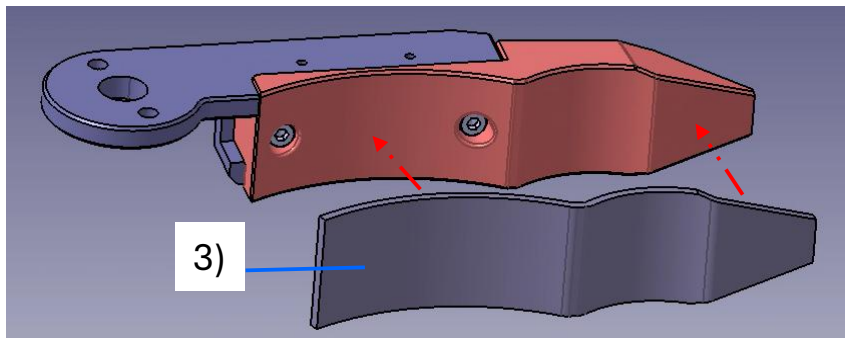
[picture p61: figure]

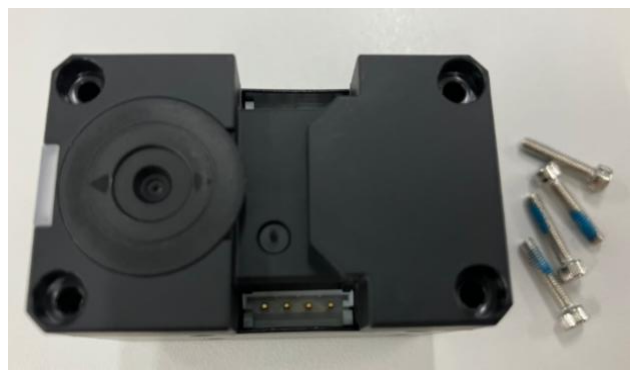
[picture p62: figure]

(6) Installation of DYNAMIXEL
- Remove bottom bolts
1) Remove the four bolts on the bottom side.
- Install BRACKET_DYNAMIXEL
2) Install BRACKET_DYNAMIXEL onto DYNAMIXEL + GEAR SHAFT ASSY (3).
Be careful not to loosen or detach the DYNAMIXEL bottom cover during assembly.
3) Secure BRACKET_DYNAMIXEL with CB2.5-15 (4 pcs). (Tighten lightly at this stage.)

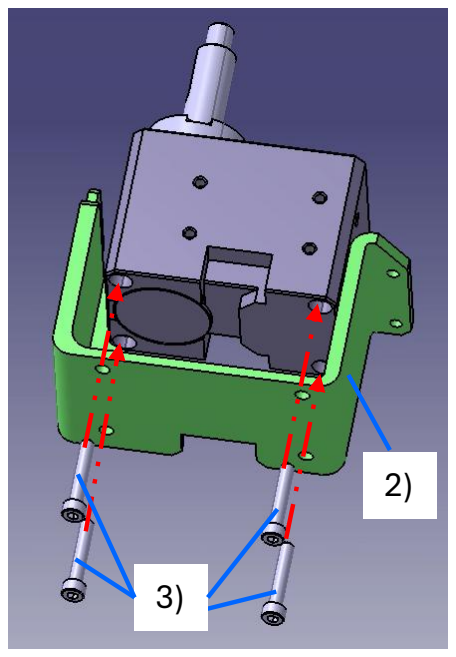
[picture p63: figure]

- Install CASE
4) Install CASE onto DYNAMIXEL + BRACKET ASSY.
5) Secure BRACKET_DYNAMIXEL with CBSTNR2-5 (4 pcs). (Torque: 0.315 N･m)

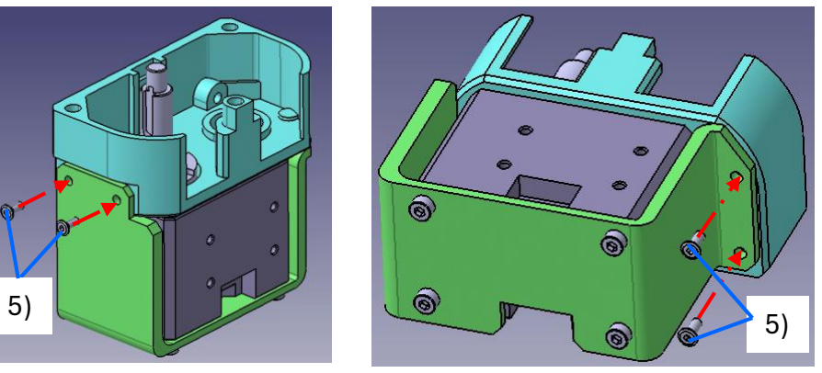
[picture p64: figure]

(7) Installation of FINGER ASSY_R (Right Finger, Step (4))
- Install SPUR GEAR
1) Install SPUR GEAR_z30 onto GEAR SHAFT.
2) Install PARALLEL KEY.

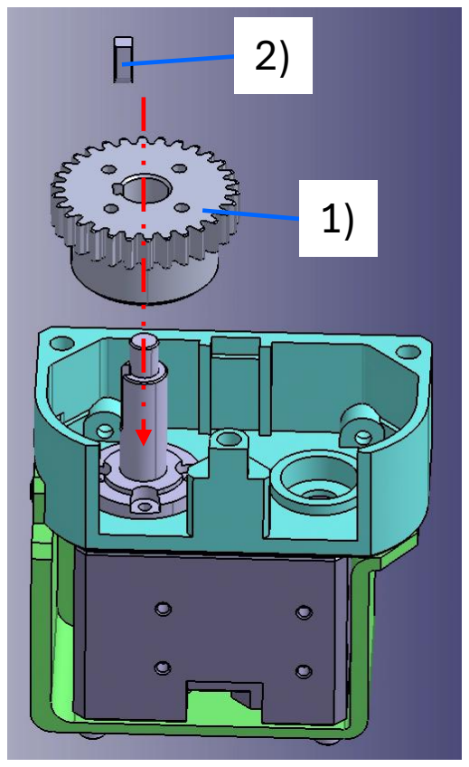
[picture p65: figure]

- Install FINGER ASSY_R
3) Install FINGER ASSY_R (4) onto GEAR SHAFT.
4) Secure FINGER ASSY_R (4) with CBSTNR3-8 (2 pcs). (Apply threadlocker, Torque: 1.14 N･m)

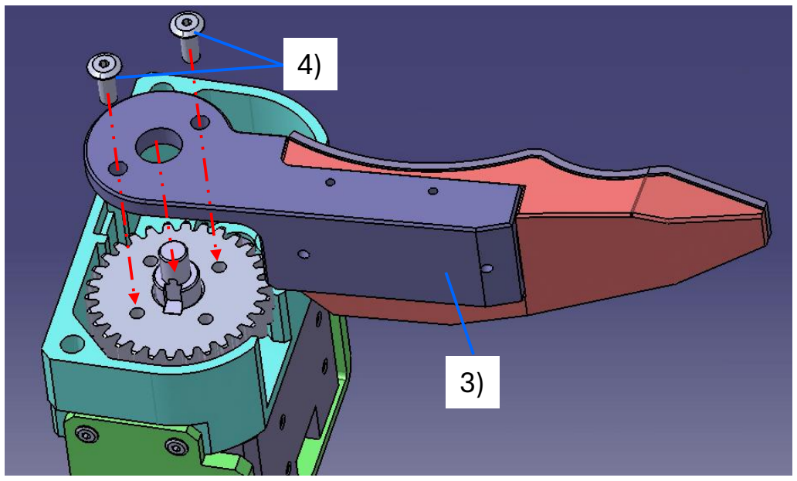
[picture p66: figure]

(8) Installation of FINGER ASSY_L (Left Finger, Step (5))
- Install SPUR GEAR
Install the following components onto the shaft of the left finger:
1) BEARING
2) WASHER
3) SHAFT_D8
4) SPUR GEAR_z30
5) PARALLEL KEY
- Install FINGER ASSY_L

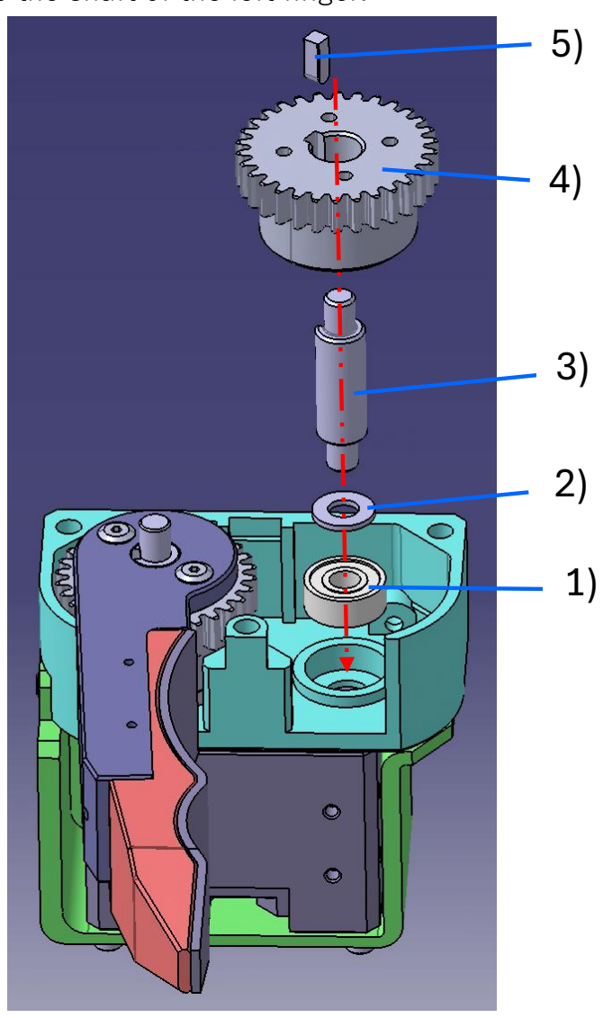
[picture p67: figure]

6) Install FINGER ASSY_L (5) onto SHAFT_D8.
7) Secure FINGER ASSY_L (5) with CBSTNR3-8 (2 pcs). (Apply threadlocker, Torque: 1.14 N･m)


(9) Installation of UPPER PLATE
- Install bearings
1) Install washers onto the shaft sections of both left and right fingers.
2) Install bearings onto the shaft sections of both left and right fingers.


- Install UPPER PLATE
3) Install UPPER PLATE.
4) Secure UPPER PLATE with CB2.5-15 (3 pcs). (Torque: 0.65 N･m)


3)

5) Tighten the DYNAMIXEL mounting bolts CB2.5-15 (4 pcs). (Torque: 0.65 N･m)


5)

(10) Installation of FLAPs
- Install FLAP_R
1) Install FLAP_R onto FINGER ATTACHMENT_R.
2) Secure FLAP_R with CB2-6 (2 pcs). (Torque: 0.315 N･m)


- Install FLAP_L
3) Install FLAP_L onto FINGER ATTACHMENT_L.
4) Secure FLAP_L with CB2-6 (2 pcs). (Torque: 0.315 N･m)


(11) Installation of CAMERA
- Install CAMERA
1) Place CAMERA onto CAMERA_BRACKET.
2) Secure CAMERA with CB2.5-6 (2 pcs). (Torque: 0.36 N･m)

CAMERA_BRACKET

2)


(12) Installation of YUBI Gripper_DYNAMIXEL onto UR5e

- Install BRACKET_GRIPPER
1) Install locating pins (JPBPB2-3: 1 pc / JPDPB2-3: 1 pc) onto BRACKET_GRIPPER.
2) Install BRACKET_GRIPPER onto the rear side of UPPER PLATE.
3) Secure BRACKET_GRIPPER with CBE3-8 (4 pcs). (Torque: 0.63 N･m)

- Install UR5e_FLANGE onto UR5e
4) Install locating pin (XDSHC6-P4-L6-B5: 1 pc) onto UR5e_FLANGE.
5) Install UR5e_FLANGE onto the UR5e tool flange.
6) Secure UR5e_FLANGE with CBE6-10 (4 pcs). (Torque: 9.2 N･m)

- Install YUBI Gripper_DYNAMIXEL onto UR5e
7) Align locating pins of BRACKET_GRIPPER with UR5e_FLANGE mounted on UR5e.
8) Secure with CBE3-8 (4 pcs). (Torque: 1.14 N･m)

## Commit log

2026-05-29 Initial commit: YUBI open source hardware release
    STEP/STL CAD files for Glove and Gripper (DYNAMIXEL version),
    BOM, assembly instructions, and project documentation.
    [BRACKET_CAMERA.stl, BRACKET_CAMERA.stp, BRACKET_DYNAMIXEL.stl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]
2026-05-31 Add Portable and Stationary data collection rigs
    Add the YUBI Portable data collection rig (chest-mounted, wearable) and the YUBI Stationary data collection desk, including STEP/STL files, BOMs, and an additional FR_FLANGE part.
    - New directories: STEP/portable, STL/portable, STL/stationary, STL/flange
    - New BOMs: docs/BOM/Portable_data_collection_BOM.csv and Stationary_data_collection_BOM.csv, following the existing YUBI Glove BOM layout with Vendor and Link columns in the two trailing slots
    - README updates: Part Overview gains the two new rigs with side-by-side thumbnails; Repository Structure lists the new directories; Contributors section adds Makoto Sugiura and Takehiko Ohkawa (AI R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
    [Display_case.STL, Display_plate.STL, FR_FLANGE.stl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]
2026-05-31 Address review comments: lowercase file extensions and capitalize roles
    - Rename STEP/portable/Chest_mount_assy.STEP to .stp to match the existing convention (lowercase, three-letter)
    - Rename four .STL files to .stl in STL/portable and STL/stationary
    - Capitalize the Role column for the two new Contributors entries (Data Collection Rig Design, Data Collection Concept Design)
    [Display_case.stl, Display_plate.stl, chest_mount_3s_hmd.stl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]
2026-06-01 fix: update Glove and Gripper BOMs
    Glove: split controller into R/L (Quest 3S), add PIN HEADER,
    SB-304550 insert, and elastic band. Gripper: specify servo model
    as XM430-W350-R. Normalize encoding to UTF-8 (no BOM) with LF.
    [YUBI Glove Assy_BOM.csv, YUBI Gripper_DYNAMIXEL_BOM.csv]
2026-06-05 fix stl data of COVER_PCB_R
    [COVER_PCB_R.stl]
2026-07-17 Update BOM table in Assembly Guide
2026-07-27 docs: replace BOM CSV with MD and add note
    [Portable_data_collection_BOM.csv, Stationary_data_collection_BOM.csv, YUBI Glove Assy_BOM.csv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]
2026-07-27 docs: replace BOM CSV with MD and add notes
2026-08-07 feature: add STL and STEP files for G1 flange
    [ANDO_G1_BRACKET_GRIPPER.stl, FR_FLANGE.stl]
2026-08-07 fix: restore deleted file
    [FR_FLANGE.stl]
2026-08-07 fix: rename files
    [BRACKET_UNITREE_G1_GRIPPER.stl, BRACKET_UNITREE_G1_GRIPPER.stp, FLANGE_FRANKA_PANDA_GLOVE.stl]
2026-08-07 feature: update flange variants
    Replace FR_FLANGE with FLANKA/OPENARM flanges and YUBI attachment,
    adding both STL and STEP formats.
    [FLANKA_FLANGE.STEP, FLANKA_FLANGE.STL, FR_FLANGE.stl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]
2026-08-13 fix: correct flange name spelling FLANKA -> FRANKA
    Rename the Franka flange assets and re-export from SolidWorks so the
    embedded STL header and STEP FILE_NAME/PRODUCT names also use the
    correct "FRANKA" spelling.
    [FLANKA_FLANGE.STEP, FLANKA_FLANGE.STL, FRANKA_FLANGE.STEP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]
2026-08-14 docs: document flange directory and supported robot flanges
    Add STEP/flange to the repository structure and a new "Supported Robot
    Flanges" section describing each robot-specific flange and the YUBI-side
    attachment used with it.
2026-08-19 fix: correct spelling FRANGE -> FLANGE
    [UNITREE_G1_FLANGE.STEP, UNITREE_G1_FLANGE.STL]
2026-09-21 feature: update YUBI v2
    [BRACKET_CAMERA.stl, BRACKET_CAMERA.stp, BRACKET_DYNAMIXEL.STEP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]
